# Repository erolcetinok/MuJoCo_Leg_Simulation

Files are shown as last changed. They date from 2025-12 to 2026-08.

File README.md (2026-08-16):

# MuJoCo Quadruped

A 3-DoF-per-leg quadruped with a tight simulation ↔ hardware parallel: one
MuJoCo model, one set of kinematics and gait code, and a backend abstraction so
the same command stream drives the simulator, real Dynamixels, or both at once.

**Current state:** the full 12-DOF software stack is written and verified in
simulation. One physical leg has been driven end-to-end on real hardware. The
four-legged robot has not been assembled yet — that's the next job.

> **Coming back to this after a while?** Read **`docs/STATUS.md`** first — it's
> the dated catch-up page (what works, what's only ever run in sim, what's next).
> Then **`docs/HANDBOOK.md`** for how the code is organised.

---

## Layout

```
configs/robot.yaml      single source of truth (joints, limits, offsets, bauds)
description/            MJCF + STL meshes (MuJoCo-Menagerie convention)
firmware/               Arduino sketches (ARCHIVED); robot_config.h is generated
scripts/                every command you run, plus codegen
src/quadruped/          the importable library
  ├── config.py         generated dataclass mirroring robot.yaml
  ├── kinematics/       fk, ik (closed-form), jacobian (DLS IK + foot force)
  ├── control/          trajectory.py, gait.py
  ├── backends/         RobotBackend ABC: Mujoco, Arduino, Dynamixel, Mirror
  ├── calibration.py    tick math, YAML patching, the guided calibration routine
  ├── cli_args.py       argparse glue shared by scripts/ (backend flags, parsers)
  ├── sim/              MuJoCo loader with YAML-consistency assertions
  └── gui/              Dear PyGui app + embedded MuJoCo renderer
tests/                  pytest
cad/                    CAD source (e.g. thigh.3mf)
```

**`scripts/` holds things you run; `src/quadruped/` holds things you import.**
There are no `quad-*` console scripts — a command is a file, and you run it with
your active interpreter, which is what you want when MuJoCo is involved.

## Quickstart

```bash
python -m venv .venv && source .venv/bin/activate
pip install -e '.[dev,gui]'      # for the dependencies; commands self-bootstrap
pytest
python scripts/codegen.py --check   # generated artifacts match robot.yaml?
```

> **macOS: windowed commands need `mjpython`, not `python`.** MuJoCo's
> interactive viewer must own the main thread. That means `view.py`, `ik_demo.py`,
> anything with `--viewer`, and `gui.py --viewer external`. Everything else —
> including plain `python scripts/gui.py`, whose embedded viewer renders
> offscreen — runs under normal `python`. `mjpython` ships with the mujoco wheel.

```bash
# Simulation only — safe, no hardware needed
python scripts/send_foot.py 20 -175 -50 --dry-run       # IK only, prints angles
mjpython scripts/send_foot.py 20 -175 -50 --backend sim --viewer
mjpython scripts/view.py --model quad
mjpython scripts/ik_demo.py --path step
python scripts/gait_demo.py --gait trot --vx 40

# Hardware — U2D2, in bringup order (see docs/hardware_bringup.md)
export SERIAL_PORT=/dev/ttyUSB0
python scripts/dxl_scan.py                              # do all 12 enumerate?
python scripts/calibrate.py --leg FL                    # guided sign/offset wizard
python scripts/calibrate.py --verify --leg FL           # did it take?
python scripts/swing_hw.py --leg FL --backend dxl --rate 33 --loop
python scripts/gait_demo.py --backend mirror --rate 33

# Sim + hardware in lockstep
mjpython scripts/send_foot.py 20 -175 -50 --backend mirror --viewer

# Slider GUI (Dear PyGui + embedded MuJoCo render)
python scripts/gui.py                                   # sim, embedded viewer
python scripts/gui.py --backend mirror                  # sim + leg together
python scripts/gui.py --backend dxl --viewer none       # sliders only
```

> **GUI viewer modes:** `embedded` (default) renders MuJoCo offscreen into a Dear
> PyGui texture — one window, one process, no second GLFW context, reliable on
> macOS. `external` launches MuJoCo's passive viewer in its own window (mouse
> camera control, but the dual-GLFW setup is fragile on macOS). `none` is
> slider-only.

## Backends

`quadruped.backends.RobotBackend` is the abstraction; pick one with `--backend`
and nothing downstream branches on the choice.

| `--backend` | Class | What it does |
| --- | --- | --- |
| `sim` | `MujocoBackend` | Writes joint angles straight to `data.qpos` and runs `mj_forward`. **Kinematic — physics is bypassed**, so it shows geometry and reach, not balance. |
| `dxl` | `DynamixelBackend` | U2D2 + DYNAMIXEL SDK, direct USB→bus. Pings all 12 on connect and checks every SDK return code. Sync read/write, present current, `foot_force(leg)`, health status. Written and unit-tested; **not yet run against a real bus.** |
| `mirror` | `MirrorBackend` | Fans one command to sim + the U2D2 together. |

`ArduinoBackend` (the UNO/SoftwareSerial bridge that brought up the first leg) is
archived: still importable, no longer reachable from a `--backend` string, and
none of the safety machinery above applies to it. See `firmware/README.md`.

## Editing the robot configuration

Joint limits, motor IDs, baud rates, zero offsets, and link lengths live in
**`configs/robot.yaml`**. Two artifacts are generated from it and committed:

- `firmware/leg_controller/robot_config.h` — `#include`d by the sketch
- `src/quadruped/config.py` — frozen dataclass imported by the package

After editing the YAML, run `python scripts/codegen.py`. `--check` mode fails if
either artifact has drifted; install the bundled hook to make drift a commit
error:

```bash
pip install pre-commit && pre-commit install
```

## Documentation

`docs/` is gitignored — it lives on this machine only, not in the repo.

| File | What it's for |
| --- | --- |
| `docs/STATUS.md` | **Start here.** Dated state of the project, what's hardware-proven vs sim-only, open gaps, next action. |
| `docs/HANDBOOK.md` | How the codebase is organised and how to work in it: mental model, repo map, the two pipelines, "I want to…" recipes, debugging playbook. |
| `docs/CLI.md` | Every command, every flag, when to reach for it. |
| `docs/INVERSE_KINEMATICS.md` | Full derivation of the closed-form solver, plus the Jacobian / DLS / foot-force math. |
| `docs/hardware_bringup.md` | **The build doc.** Components, wiring diagram, gauge per connection, bringup runbook. |
| `docs/power_rationale.md` | Why those parts, what was cut, research sources. |
| `firmware/README.md` | Arduino UNO bridge path (ARCHIVED), end to end. |

## Hardware

The hardware is a Raspberry Pi 5 + U2D2 driving twelve XL430-W250 servos.
`docs/hardware_bringup.md` has the components, the wiring diagram with a gauge per
connection, and the ordered bringup runbook. That stack is final; all remaining
work on this project is software. The Arduino UNO R3 + Dynamixel Shield bridge
that brought up the first leg is archived in `firmware/README.md`.

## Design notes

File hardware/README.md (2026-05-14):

# Single-leg hardware setup

Start-to-finish bring-up for the 3-DoF leg: three daisy-chained Dynamixels driven by an Arduino UNO R3, commanded over USB from your Mac. Joint order everywhere is **shoulder → wing → knee**, same as `meshes/single_leg.xml`.

The Arduino's onboard USB is **flash-only** for this project. Host comms (commands and replies) go through a small USB-to-TTL adapter wired to the Arduino's D7/D8 pins. The reason: on UNO R3, the Dynamixel Shield and the onboard USB-UART chip both live on the same hardware UART (D0/D1) and electrically fight each other for D0 — you cannot reliably read host bytes through the Arduino's USB while the shield is driving the DXL bus. See §5 for the full explanation. The adapter sidesteps the problem cleanly by putting host comms on a second, dedicated serial path that ROBOTIS designed the shield for.

---

## 1. Parts

| Part | Notes |
|---|---|
| **Arduino UNO R3** | ATmega328P. Onboard USB used for flashing only. |
| **ROBOTIS DYNAMIXEL Shield** | TTL half-duplex driver + screw terminals + UART switch + Dynamixel power switch. |
| **3 × XL430-W250-T** servos | Daisy-chained. IDs **1 / 2 / 3** (shoulder / wing / knee), **Protocol 2.0**, **baud 115 200**. |
| **3-pin TTL JST cables** | XL430 uses TTL only — **never** the 4-pin RS-485 port on the shield. |
| **USB-to-TTL adapter** | CP2102, CH340, or FTDI. Any cheap module from Amazon. Carries host commands and replies. |
| **3× M/F jumper wires** | "Dupont" cables to connect adapter ↔ Arduino. |
| **Bench supply** | **6.5–12.0 V** (XL430's spec — the shield itself accepts 5–24 V, but the motors don't), ~5 A capable for three XL-class motors under load. **Do not exceed 12.0 V.** |
| **USB-B cable** | UNO R3 to your Mac (flashing). |
| **USB-A cable for the adapter** | Whatever the adapter takes (USB-A or USB-C). |

Official references (only consult if something doesn't match below):
- [ROBOTIS DYNAMIXEL Shield](https://emanual.robotis.com/docs/en/parts/interface/dynamixel_shield/) — switches, jumpers, connectors.
- [XL430-W250-T](https://emanual.robotis.com/docs/en/dxl/x/xl430-w250/) — voltage, control table.

---

## 2. Mac-side install

1. Install [Arduino IDE 2](https://www.arduino.cc/en/software).
2. **Tools → Board → Boards Manager** → install **Arduino AVR Boards** (it's usually pre-installed; Arduino UNO appears under it).
3. **Tools → Manage Libraries** → install **Dynamixel2Arduino**.
4. From the repo root (the directory containing `requirements.txt`, one level above `hardware/`): `pip install -r requirements.txt` — needed for the helper scripts in `scripts/`.
5. macOS bundles drivers for CP2102 and FTDI out of the box (macOS 11+). For CH340 modules, install [WCH's signed driver](https://www.wch-ic.com/downloads/CH34XSER_MAC_ZIP.html) if your adapter doesn't enumerate.

---

## 3. Configure the servos (IDs, baud, protocol)

Each motor must end up at **ID 1 / 2 / 3**, **baud 115 200**, **Protocol 2.0**. Factory defaults are **ID 1, baud 57 600** — three fresh XL430s on the same bus will all answer to ID 1 and collide, which is why you configure one motor at a time below.

> Why 115 200 and not 1 Mbps (the XL430's nominal max)? Because the hardware Serial bus only carries DXL traffic now (host is on the adapter), 1 Mbps is technically usable — but motors and sketches currently default to 115 200 and there's no benefit at this scale. Stick with 115 200 unless you have a reason.

**You need the shield powered and wired first** — do section 4, then come back here before uploading `leg_controller.ino`.

Use the repo-local helper sketch `hardware/configure_motor/configure_motor.ino`. It probes the motor across 57 600 / 115 200 / 1 000 000, sets it to your target ID, then changes its baud to 115 200 — all in one upload. Output prints to the adapter's terminal at **57 600** (host link baud — see §5).

Procedure — repeat three times:

1. **Disconnect all motors except the one you're configuring.** Plug only motor #1 (or #2 or #3 — they're all identical at this point) into the shield's TTL jack.
2. Open `hardware/configure_motor/configure_motor.ino`.
3. Edit `#define SOURCE_ID` (match the motor's current ID, or 1 for factory-fresh) and `#define TARGET_ID` — **1** for shoulder, **2** for wing, **3** for knee.
4. Set UART switch to **Upload**, click **Upload** in the IDE.
5. Flip UART switch to **DYNAMIXEL**, press **RESET**, wait ~3 seconds.
6. Open a terminal on the adapter's port at **57600** baud (`python scripts/usb_console.py` does this, or any terminal of your choice). You should see `OK: motor at ID <n>, baud 115200` — the 115200 here is the *motor's* baud, which is independent of the host link.
7. Unplug that motor, plug in the next one, change `TARGET_ID`, repeat from step 4.

If you see `FAIL: no motor at ID <n> (tried baud 57600, 115200, 1000000)`, the motor is at an unexpected baud (run `find_motor.ino`), or power/cable/switch isn't right. If you see `FAIL: setID` or `FAIL: setBaudrate`, power-cycle the motor and try again — partial configuration is normal and the sketch handles it.

---

## 4. Physical assembly (power OFF)

1. Stack the **Dynamixel Shield** onto the UNO R3. Press until fully seated.
2. **Remove the VIN jumper cap** from the shield ("Disconnect VIN" mode) so Dynamixel power comes only from the shield's screw terminals, not the Arduino VIN path.
3. Wire bench supply **+ / −** to the shield's Dynamixel power screw terminals, matching the silkscreen exactly. Wrong polarity destroys hardware. Leave the supply OFF.
4. Daisy-chain the servos: **shield's 3-pin TTL JST socket → servo 1 (in) → servo 1 (out) → servo 2 (in) → servo 2 (out) → servo 3 (in)**. Mechanical order does not set IDs — that's done in section 3.
   - Use a **3-pin TTL** jack on the shield. The 4-pin RS-485 jack will not work with XL430-T.
5. Wire the **USB-to-TTL adapter** to the shield's exposed pin headers using three jumper wires:
   - adapter **TX**  → Arduino **D7**
   - adapter **RX**  → Arduino **D8**
   - adapter **GND** → Arduino **GND**
   - adapter **VCC** → **leave disconnected** (Arduino is powered via its own USB).
6. Plug both USB cables into your Mac:
   - **Arduino USB-B** → flashing.
   - **Adapter USB**   → host commands + sketch output.

```
   [ USB-to-TTL adapter ]                      [ Dynamixel Shield ]
     TX RX GND                                 ← 3-pin TTL JST to servos
      |  |  |
      |  |  └─── Arduino GND
      |  └─────── Arduino D8  (sketch TX)
      └────────── Arduino D7  (sketch RX)
                          ↑
                  [ Arduino UNO R3 ]
                          ↑
                       USB-B to Mac (flashing only)
```

---

## 5. How the dual-serial setup works (read before uploading)

UNO R3 has one hardware UART (`Serial` on D0/D1). The Dynamixel Shield uses those same pins for the DXL bus. **At runtime, the hardware Serial carries DXL bus traffic only** — the shield's transceiver actively drives D0/D1, and any other source on those pins gets electrically overridden.

That's why host comms go through `SoftwareSerial(7, 8)` and the USB-to-TTL adapter on D7/D8. The adapter exposes its own `/dev/cu.usbserial*` (or `/dev/cu.SLAB_USBtoUART`) port on your Mac, and that's the port your terminal, `send_angles.py`, and `jog.py` talk to. The Arduino's onboard USB-B (`/dev/cu.usbmodem*`) is used only for flashing.

**Host link runs at 57 600 baud.** All sketches and Python scripts default to this. `SoftwareSerial` on a 16 MHz AVR is too unreliable at 115 200 in practice — bytes get dropped or corrupted, especially on the Mac→Arduino direction. 57 600 is the documented fallback and works cleanly. The DXL bus on hardware Serial stays at 115 200, independent of the host link.

What this means in practice:
- The shield's **UART switch sits on DYNAMIXEL** during normal operation. Only flip to Upload for flashing.
- **Do not try to talk to the Arduino via its onboard USB monitor at runtime.** It's wired into the same UART the shield uses, so anything you type there gets blocked by the shield's transceiver. The adapter is the only host-comm path.
- `SoftwareSerial` occasionally still injects phantom noise bytes before a real line begins; `leg_controller.ino`'s loop discards anything before the `q,` prefix to defend against this.
- `sscanf("%f", ...)` is **not linked** in the default Arduino AVR build — `leg_controller.ino` parses floats with `strtod` instead. Don't switch back to `sscanf %f`; it'll silently fail.

---

## 6. Upload firmware

1. Open `hardware/leg_controller/leg_controller.ino` in Arduino IDE.
2. **Tools → Board → Arduino AVR Boards → Arduino UNO**.
3. **Tools → Port** → the **Arduino's** USB device (`/dev/cu.usbmodem...`). This is for flashing only; not the adapter's port.
4. Set UART switch on shield to **Upload**.
5. Click **Upload**. Wait for it to finish.
6. Set UART switch to **DYNAMIXEL**.
7. **Support the leg by hand** — when the first command lands, motors will snap to whatever position you send. Don't let it whip into something.
8. Turn the bench supply **ON** (correct voltage), then turn the shield's **Dynamixel power switch ON**.
9. Press **RESET** on the Arduino once.

---

## 7. Verify the controller is alive

Open a terminal on the **adapter's** port at **57600** baud. The easiest way:

```bash
python scripts/usb_console.py --port /dev/cu.usbserial-XXXX
```

(or run `python scripts/usb_console.py --list` to see what's plugged in — pick the adapter's port, not the Arduino's `/dev/cu.usbmodem*`).

Expected output after reset:

```
the controller is ready
dynamixels ready
mode: usb command (q,q1,q2,q3)
```

Then send `q,0.0,0.0,0.0` + Enter (line ending Newline). Reply should be `ok 0.00 0.00 0.00` and the leg snaps to the zero pose.

**If the terminal is blank or shows nothing:** baud rate or wrong port. Confirm 57 600 and that you picked the adapter's port. If still blank, double-check the three jumper wires (TX↔D7, RX↔D8, GND↔GND).

**If you see `? no servo ID <n>`** for any motor: IDs / baud / protocol don't match the firmware, or UART switch is still on Upload, or shield power is off, or the cable is in the RS-485 jack. Re-check sections 3, 4, and 6.

---

## 8. Drive the leg from Python

One-shot:

```bash
python scripts/send_angles.py 0.0 0.0 0.0 --port /dev/cu.usbserial-XXXX
```

Or set the port once per terminal session:

```bash
export SERIAL_PORT=/dev/cu.usbserial-XXXX
python scripts/send_angles.py 0.1 -0.2 0.5
```

Interactive (no per-command lag — port stays open):

```bash
python scripts/jog.py --port /dev/cu.usbserial-XXXX
```

```
> 0 0 0
  ok 0.00 0.00 0.00
> 0.5 -0.3 0.2
  ok 0.50 -0.30 0.20
```

`scripts/usb_console.py` is a terminal replacement for Arduino Serial Monitor — useful for one-off inspection. All three scripts default to baud **57 600** to match the sketch.

---

## 9. Protocol

- One line per command: `q,<q1>,<q2>,<q3>`, radians, newline-terminated.
- Reply: `ok <q1> <q2> <q3>` (echo of clamped values), or `? bad format` / `? no servo ID <n>`.
- Joint limits (radians, enforced by the Arduino):

  | Joint | Min | Max |
  |-------|-----|-----|
  | Shoulder | −π/2 | +π/2 |
  | Wing | −0.873 (≈ −50°) | +0.873 (≈ +50°) |
  | Knee | −2.007 (≈ −115°) | +π/2 |

Limits match `meshes/single_leg.xml`.

Motion speed is firmware-set, not commanded: `leg_controller.ino` writes `PROFILE_VELOCITY = 40` to each motor in `setup()`. Edit that constant in the sketch if you want faster/slower trajectories — the Python side has no speed parameter.

---

## 10. Calibration

`leg_controller.ino` ships with `OFFSET_SHOULDER_DEG = OFFSET_WING_DEG = OFFSET_KNEE_DEG = 180.0f`. That maps `q = 0 rad` to motor position 180° — the geometric middle of `OP_POSITION`'s 0–360° range. Around that neutral, each joint's full radian limit lands inside the motor's reachable range:

| Joint | Range from q=0 | Motor degrees |
|---|---|---|
| Shoulder | ±π/2 (±90°) | 90°–270° |
| Wing | ±0.873 (±50°) | 130°–230° |
| Knee | −2.007 to +π/2 (−115° to +90°) | 65°–270° |

**Physical assembly assumption:** when you mount the leg links to the horns, do it with the motor sitting at 180° (its electrical midpoint). Then "q=0 across the board" produces the sim's zero pose mechanically.

If you remount a motor or the sim's zero diverges from the physical neutral, recalibrate by editing the three `OFFSET_*_DEG` constants:

1. Power the bus, leave the motors **torque off** (or just observe present positions before commands move them).
2. By hand, move the leg to the sim's zero pose.
3. Read the boot-time `ID <n> pos deg=...` line printed by `setup()` — that's the motor's current degree value.
4. Use that value as the new `OFFSET_*_DEG` for that joint.

---

## 11. ~~Known issue — knee can't reach negative angles yet~~ Resolved

Previously, the knee's `−2.007 rad (≈ −115°)` minimum was unreachable because `OP_POSITION` is single-turn 0–360° and negative degrees clamp to 0. The 180° offset in §10 fixes this: `−115°` from neutral lands at motor `65°`, well inside the range. No `OP_EXTENDED_POSITION` switch needed.

---

## 12. Safety

- **Do not exceed 12.0 V** on the Dynamixel bus.
- **Do not hot-plug Dynamixel cables** while shield power is on.
- **Polarity** on the shield's power terminals must match the silkscreen.
- Restrain the leg before the first command — motors snap to goal positions immediately.

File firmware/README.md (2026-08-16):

# Arduino UNO bridge — hardware setup (ARCHIVED)

> **This path is retired.** The robot runs Raspberry Pi 5 + U2D2, driving the
> servos directly over the DYNAMIXEL SDK — see `docs/hardware_bringup.md` for the
> BOM and bringup order, and `docs/power_and_electronics.md` for the power chain.
> `--backend hw` no longer exists; `dxl` and `mirror` are the hardware choices.
>
> Everything here still works and is what the first leg was brought up on, so it
> is kept for the old UNO rig. It gets no new features, and the safety work added
> for the U2D2 path (ping-on-connect, stand-up ramp, e-stop freeze, torque
> release, health monitoring) is **not** present on this path.

Start-to-finish bring-up for the Arduino path: up to twelve daisy-chained
Dynamixels driven by an Arduino UNO R3, commanded over USB from your Mac.
Joint order everywhere is the canonical YAML order — legs **FL, FR, BL, BR** ×
joints **shoulder, wing, knee** — the same order used by the wire format, the
`syncWrite` packet, and `configs/robot.yaml`.

If you're bringing up a single leg on the bench, wire only FL (IDs 1-3); the
sketch reports `? no servo ID <n>` for the absent motors at boot and keeps
going.

The Arduino's onboard USB is **flash-only** for this project. Host comms (commands and replies) go through a small USB-to-TTL adapter wired to the Arduino's D7/D8 pins. The reason: on UNO R3, the Dynamixel Shield and the onboard USB-UART chip both live on the same hardware UART (D0/D1) and electrically fight each other for D0 — you cannot reliably read host bytes through the Arduino's USB while the shield is driving the DXL bus. See §5 for the full explanation. The adapter sidesteps the problem cleanly by putting host comms on a second, dedicated serial path that ROBOTIS designed the shield for.

---

## 1. Parts

| Part | Notes |
|---|---|
| **Arduino UNO R3** | ATmega328P. Onboard USB used for flashing only. |
| **ROBOTIS DYNAMIXEL Shield** | TTL half-duplex driver + screw terminals + UART switch + Dynamixel power switch. |
| **12 × XL430-W250-T** servos | Daisy-chained. IDs **1-12** in per-leg blocks (FL 1-3, FR 4-6, BL 7-9, BR 10-12), each block shoulder / wing / knee. **Protocol 2.0**, **baud 115 200**. |
| **3-pin TTL JST cables** | XL430 uses TTL only — **never** the 4-pin RS-485 port on the shield. |
| **USB-to-TTL adapter** | CP2102, CH340, or FTDI. Any cheap module from Amazon. Carries host commands and replies. |
| **3× M/F jumper wires** | "Dupont" cables to connect adapter ↔ Arduino. |
| **Bench supply** | **6.5–12.0 V** (XL430's spec — the shield itself accepts 5–24 V, but the motors don't). ~5 A is enough for one leg on the bench; a full twelve-motor robot needs far more headroom — see `docs/power_and_electronics.md`. **Do not exceed 12.0 V.** |
| **USB-B cable** | UNO R3 to your Mac (flashing). |
| **USB-A cable for the adapter** | Whatever the adapter takes (USB-A or USB-C). |

Official references (only consult if something doesn't match below):
- [ROBOTIS DYNAMIXEL Shield](https://emanual.robotis.com/docs/en/parts/interface/dynamixel_shield/) — switches, jumpers, connectors.
- [XL430-W250-T](https://emanual.robotis.com/docs/en/dxl/x/xl430-w250/) — voltage, control table.

---

## 2. Mac-side install

1. Install [Arduino IDE 2](https://www.arduino.cc/en/software).
2. **Tools → Board → Boards Manager** → install **Arduino AVR Boards** (it's usually pre-installed; Arduino UNO appears under it).
3. **Tools → Manage Libraries** → install **Dynamixel2Arduino**.
4. From the repo root (the directory containing `pyproject.toml`, one level above `firmware/`): `pip install -e .` — installs the `quadruped` Python package and pulls in pyserial/numpy/mujoco for the host-side scripts.
5. macOS bundles drivers for CP2102 and FTDI out of the box (macOS 11+). For CH340 modules, install [WCH's signed driver](https://www.wch-ic.com/downloads/CH34XSER_MAC_ZIP.html) if your adapter doesn't enumerate.

---

## 3. Configure the servos (IDs, baud, protocol)

Each motor must end up at a **unique ID in 1-12**, **baud 115 200**, **Protocol 2.0**. Factory defaults are **ID 1, baud 57 600** — fresh XL430s on the same bus will all answer to ID 1 and collide, which is why you configure one motor at a time below.

The ID map is fixed by `configs/robot.yaml` and must match exactly:

| Leg | Shoulder | Wing | Knee |
|-----|---|---|---|
| FL  | 1 | 2 | 3 |
| FR  | 4 | 5 | 6 |
| BL  | 7 | 8 | 9 |
| BR  | 10 | 11 | 12 |

Label each motor physically as you configure it. Twelve identical servos on a bench with no labels is a bad afternoon.

> Why 115 200 and not 1 Mbps (the XL430's nominal max)? Because the hardware Serial bus only carries DXL traffic now (host is on the adapter), 1 Mbps is technically usable — but motors and sketches currently default to 115 200 and there's no benefit at this scale. Stick with 115 200 unless you have a reason.

**You need the shield powered and wired first** — do section 4, then come back here before uploading `leg_controller.ino`.

> Joint limits, motor IDs, baud rates, and zero offsets all live in `configs/robot.yaml` and are codegen'd into `firmware/leg_controller/robot_config.h` (which the sketch `#include`s). To change any of them, edit the YAML and run `python scripts/codegen.py` — do not hand-edit the `.h` file.

Use the repo-local helper sketch `firmware/configure_motor/configure_motor.ino`. It probes the motor across 57 600 / 115 200 / 1 000 000, sets it to your target ID, then changes its baud to 115 200 — all in one upload. Output prints to the adapter's terminal at **57 600** (host link baud — see §5).

Procedure — repeat once per motor (up to twelve times):

1. **Disconnect all motors except the one you're configuring.** Plug only that motor into the shield's TTL jack — they're all identical at this point.
2. Open `firmware/configure_motor/configure_motor.ino`.
3. Edit `#define SOURCE_ID` (match the motor's current ID, or 1 for factory-fresh) and `#define TARGET_ID` — the value from the ID table above.
4. Set UART switch to **Upload**, click **Upload** in the IDE.
5. Flip UART switch to **DYNAMIXEL**, press **RESET**, wait ~3 seconds.
6. Open a terminal on the adapter's port at **57600** baud (`python scripts/usb_console.py` does this, or any terminal of your choice). You should see `OK: motor at ID <n>, baud 115200` — the 115200 here is the *motor's* baud, which is independent of the host link.
7. Unplug that motor, plug in the next one, change `TARGET_ID`, repeat from step 4.

If you see `FAIL: no motor at ID <n> (tried baud 57600, 115200, 1000000)`, the motor is at an unexpected baud (run `find_motor.ino`), or power/cable/switch isn't right. If you see `FAIL: setID` or `FAIL: setBaudrate`, power-cycle the motor and try again — partial configuration is normal and the sketch handles it.

---

## 4. Physical assembly (power OFF)

1. Stack the **Dynamixel Shield** onto the UNO R3. Press until fully seated.
2. **Remove the VIN jumper cap** from the shield ("Disconnect VIN" mode) so Dynamixel power comes only from the shield's screw terminals, not the Arduino VIN path.
3. Wire bench supply **+ / −** to the shield's Dynamixel power screw terminals, matching the silkscreen exactly. Wrong polarity destroys hardware. Leave the supply OFF.
4. Daisy-chain the servos: **shield's 3-pin TTL JST socket → servo 1 (in) → servo 1 (out) → servo 2 (in) → servo 2 (out) → servo 3 (in)**. Mechanical order does not set IDs — that's done in section 3.
   - Use a **3-pin TTL** jack on the shield. The 4-pin RS-485 jack will not work with XL430-T.
5. Wire the **USB-to-TTL adapter** to the shield's exposed pin headers using three jumper wires:
   - adapter **TX**  → Arduino **D7**
   - adapter **RX**  → Arduino **D8**
   - adapter **GND** → Arduino **GND**
   - adapter **VCC** → **leave disconnected** (Arduino is powered via its own USB).
6. Plug both USB cables into your Mac:
   - **Arduino USB-B** → flashing.
   - **Adapter USB**   → host commands + sketch output.

```
   [ USB-to-TTL adapter ]                      [ Dynamixel Shield ]
     TX RX GND                                 ← 3-pin TTL JST to servos
      |  |  |
      |  |  └─── Arduino GND
      |  └─────── Arduino D8  (sketch TX)
      └────────── Arduino D7  (sketch RX)
                          ↑
                  [ Arduino UNO R3 ]
                          ↑
                       USB-B to Mac (flashing only)
```

---

## 5. How the dual-serial setup works (read before uploading)

UNO R3 has one hardware UART (`Serial` on D0/D1). The Dynamixel Shield uses those same pins for the DXL bus. **At runtime, the hardware Serial carries DXL bus traffic only** — the shield's transceiver actively drives D0/D1, and any other source on those pins gets electrically overridden.

That's why host comms go through `SoftwareSerial(7, 8)` and the USB-to-TTL adapter on D7/D8. The adapter exposes its own `/dev/cu.usbserial*` (or `/dev/cu.SLAB_USBtoUART`) port on your Mac, and that's the port your terminal, `send_angles.py`, and `jog.py` talk to. The Arduino's onboard USB-B (`/dev/cu.usbmodem*`) is used only for flashing.

**Host link runs at 57 600 baud.** All sketches and Python scripts default to this. `SoftwareSerial` on a 16 MHz AVR is too unreliable at 115 200 in practice — bytes get dropped or corrupted, especially on the Mac→Arduino direction. 57 600 is the documented fallback and works cleanly. The DXL bus on hardware Serial stays at 115 200, independent of the host link.

What this means in practice:
- The shield's **UART switch sits on DYNAMIXEL** during normal operation. Only flip to Upload for flashing.
- **Do not try to talk to the Arduino via its onboard USB monitor at runtime.** It's wired into the same UART the shield uses, so anything you type there gets blocked by the shield's transceiver. The adapter is the only host-comm path.
- `SoftwareSerial` occasionally still injects phantom noise bytes before a real line begins; `leg_controller.ino`'s loop discards anything before the `q,` prefix to defend against this.
- `sscanf("%f", ...)` is **not linked** in the default Arduino AVR build — `leg_controller.ino` parses floats with `strtod` instead. Don't switch back to `sscanf %f`; it'll silently fail.

---

## 6. Upload firmware

1. Open `firmware/leg_controller/leg_controller.ino` in Arduino IDE.
2. **Tools → Board → Arduino AVR Boards → Arduino UNO**.
3. **Tools → Port** → the **Arduino's** USB device (`/dev/cu.usbmodem...`). This is for flashing only; not the adapter's port.
4. Set UART switch on shield to **Upload**.
5. Click **Upload**. Wait for it to finish.
6. Set UART switch to **DYNAMIXEL**.
7. **Support the leg by hand** — when the first command lands, motors will snap to whatever position you send. Don't let it whip into something.
8. Turn the bench supply **ON** (correct voltage), then turn the shield's **Dynamixel power switch ON**.
9. Press **RESET** on the Arduino once.

---

## 7. Verify the controller is alive

Open a terminal on the **adapter's** port at **57600** baud. The easiest way:

```bash
python scripts/usb_console.py --port /dev/cu.usbserial-XXXX
```

(or run `python scripts/usb_console.py --list` to see what's plugged in — pick the adapter's port, not the Arduino's `/dev/cu.usbmodem*`).

Expected output after reset:

```
the controller is ready
ID 1 pos ticks=2048 deg=180.00
... (one line per motor found)
dynamixels ready (12 joints)
mode: usb command (q,q0,...,qN-1)
```

Then send twelve zeros + Enter (line ending Newline):

```
q,0,0,0,0,0,0,0,0,0,0,0,0
```

Reply should be `ok` followed by the twelve clamped values, and the legs snap to
the zero pose. Sending fewer than twelve values is rejected with
`? bad format at index <i>` or `? missing comma at index <i>`.

**If the terminal is blank or shows nothing:** baud rate or wrong port. Confirm 57 600 and that you picked the adapter's port. If still blank, double-check the three jumper wires (TX↔D7, RX↔D8, GND↔GND).

**If you see `? no servo ID <n>`** for any motor: IDs / baud / protocol don't match the firmware, or UART switch is still on Upload, or shield power is off, or the cable is in the RS-485 jack. Re-check sections 3, 4, and 6.

---

## 8. Drive the leg from Python

One-shot:

```bash
python scripts/send_angles.py 0.0 0.0 0.0 --port /dev/cu.usbserial-XXXX
```

Or set the port once per terminal session:

```bash
export SERIAL_PORT=/dev/cu.usbserial-XXXX
python scripts/send_angles.py 0.1 -0.2 0.5
```

Interactive (no per-command lag — port stays open), picking the leg:

```bash
python scripts/jog.py --leg FL --backend hw --port /dev/cu.usbserial-XXXX
```

```
> 0 0 0
  ok 0.000 0.000 0.000 ...
> 0.5 -0.3 0.2
  ok 0.500 -0.300 0.200 ...
```

You type three angles; they go to the chosen leg's shoulder/wing/knee, and the
other nine joints hold their cached pose. The reply echoes all twelve.

> `send_angles.py` and `send_foot.py` take the same `--leg` flag, defaulting to
> `FL`.

For a full step cycle rather than static poses, use `scripts/swing_hw.py
--backend hw --rate 33 --loop`.

`scripts/usb_console.py` is a terminal replacement for Arduino Serial Monitor — useful for one-off inspection. All of these default to baud **57 600** to match the sketch.

---

## 9. Protocol

- One line per command: `q,<q0>,<q1>,...,<q11>` — **twelve** radian values,
  newline-terminated, in canonical order (FL, FR, BL, BR × shoulder, wing, knee).
- Reply: `ok` followed by the twelve clamped values. Errors:
  `? bad format; use q,q0,q1,...`, `? bad format at index <i>`,
  `? missing comma at index <i>`, `? no servo ID <n>`, `? syncWrite failed err=<code>`.
- All twelve goals go out in **one `syncWrite` packet**, which is the point of
  the multi-leg refactor — twelve separate `setGoalPosition()` calls would not
  fit the timing budget.
- Joint limits (radians, enforced by the Arduino, identical for every leg):

  | Joint | Min | Max |
  |-------|-----|-----|
  | Shoulder | −π/2 | +π/2 |
  | Wing | −0.873 (≈ −50°) | +0.873 (≈ +50°) |
  | Knee | −2.007 (≈ −115°) | +π/2 |

Limits, IDs, offsets, and directions all come from `robot_config.h`, generated
from `configs/robot.yaml`. They are asserted against the MJCF at model-load
time, so sim and firmware can't silently disagree.

**This link is fire-and-forget by design.** `SoftwareSerial` drops roughly 15%
of host bytes while the DXL bus is busy, so `ArduinoBackend` does not wait for
the `ok` echo — a dropped command is simply superseded by the next one at the
streaming rate. Measured round-trip is ~19 ms, giving a practical ceiling of
**40–50 Hz**; use `--rate 33`. If you need reliable feedback, use the U2D2 path.

Motion speed is firmware-set, not commanded: `leg_controller.ino` writes
`PROFILE_VELOCITY = 0` to each motor in `setup()`. Zero means "no profile" —
the servo goes to each goal as fast as it can, which is what you want when the
host is streaming a smooth trajectory at 33 Hz and the profile would otherwise
fight it. Raise it only for slow, discrete moves.

---

## 10. Calibration

> **Do this with `scripts/calibrate.py` if you have a U2D2.** The guided wizard
> walks a whole leg — offset *and* direction sign — and writes the results
> straight into `configs/robot.yaml`:
>
> ```bash
> python scripts/view.py --model quad &     # visual reference for "zero pose"
> python scripts/calibrate.py --leg FR
> python scripts/codegen.py                 # regenerate robot_config.h, then reflash
> ```
>
> The manual procedure below is the Arduino-path equivalent, and is what FL was
> originally calibrated with on 2026-05-14.

Offsets and direction signs are **per joint**, generated into
`robot_config.h` as `OFFSETS_DEG[N_JOINTS]` and `DIRS[N_JOINTS]` from the
`offset_deg` / `direction` fields in `configs/robot.yaml`. They all currently
ship at `180.0` / `+1`. That maps `q = 0 rad` to motor position 180° — the
geometric middle of `OP_POSITION`'s 0–360° range. Around that neutral, each
joint's full radian limit lands inside the motor's reachable range:

| Joint | Range from q=0 | Motor degrees |
|---|---|---|
| Shoulder | ±π/2 (±90°) | 90°–270° |
| Wing | ±0.873 (±50°) | 130°–230° |
| Knee | −2.007 to +π/2 (−115° to +90°) | 65°–270° |

**Physical assembly assumption:** when you mount the leg links to the horns, do it with the motor sitting at 180° (its electrical midpoint). Then "q=0 across the board" produces the sim's zero pose mechanically.

If you remount a motor or the sim's zero diverges from the physical neutral,
recalibrate that joint:

1. Power the bus, leave the motors **torque off** (or just observe present positions before commands move them).
2. By hand, move the leg to the sim's zero pose.
3. Read the boot-time `ID <n> pos deg=...` line printed by `setup()` — that's the motor's current degree value.
4. Put that value in the joint's `offset_deg` in **`configs/robot.yaml`** (not in the sketch, and not in `robot_config.h` — that file is generated).
5. `python scripts/codegen.py`, then reflash.

If the joint moves the *opposite* way from the model, flip its `direction` from
`1` to `-1` in the same YAML line and regenerate. The firmware applies it as
`deg = DIRS[i] * q[i] * 180/π + OFFSETS_DEG[i]`.

---

## 11. ~~Known issue — knee can't reach negative angles yet~~ Resolved

Previously, the knee's `−2.007 rad (≈ −115°)` minimum was unreachable because `OP_POSITION` is single-turn 0–360° and negative degrees clamp to 0. The 180° offset in §10 fixes this: `−115°` from neutral lands at motor `65°`, well inside the range. No `OP_EXTENDED_POSITION` switch needed.

---

## 12. Safety

- **Do not exceed 12.0 V** on the Dynamixel bus.
- **Do not hot-plug Dynamixel cables** while shield power is on.
- **Polarity** on the shield's power terminals must match the silkscreen.
- Restrain the leg before the first command — motors snap to goal positions immediately.

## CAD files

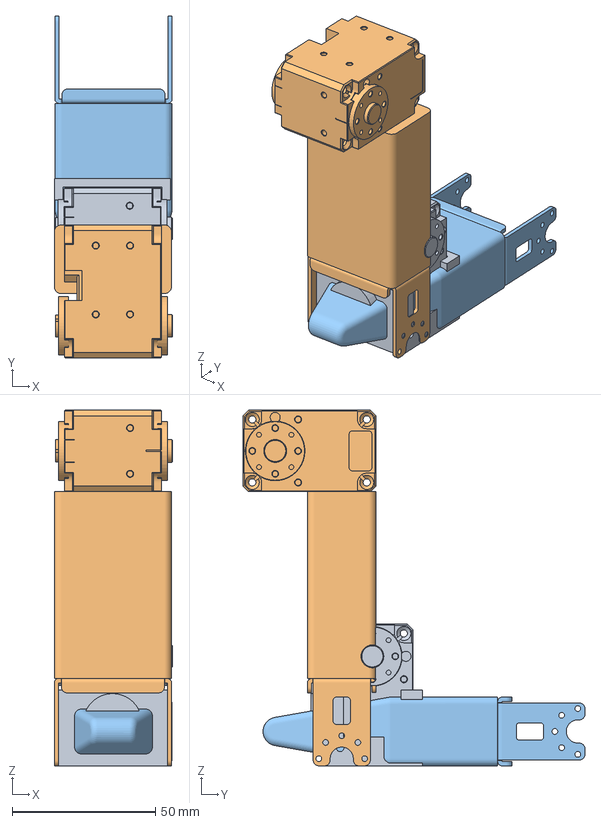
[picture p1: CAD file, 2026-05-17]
cad/thigh.3mf
41.4 x 119.5 x 124.3 mm
shoulder.STL
thigh.STL
foot.STL

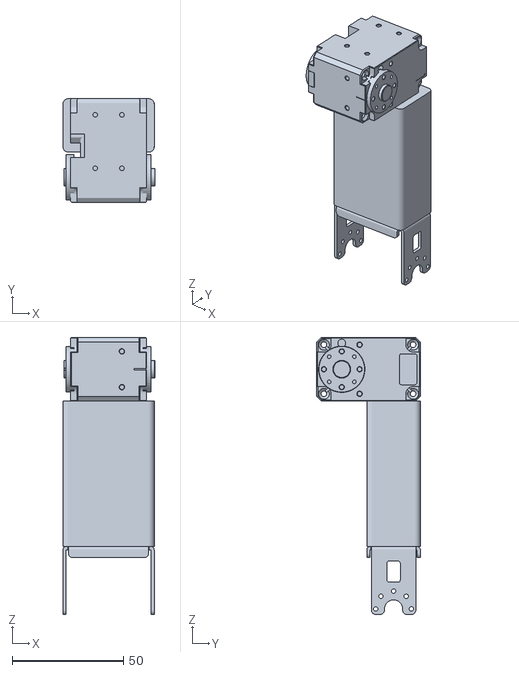
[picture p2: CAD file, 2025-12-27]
description/meshes/thigh.STL
41.4 x 46.5 x 124.3

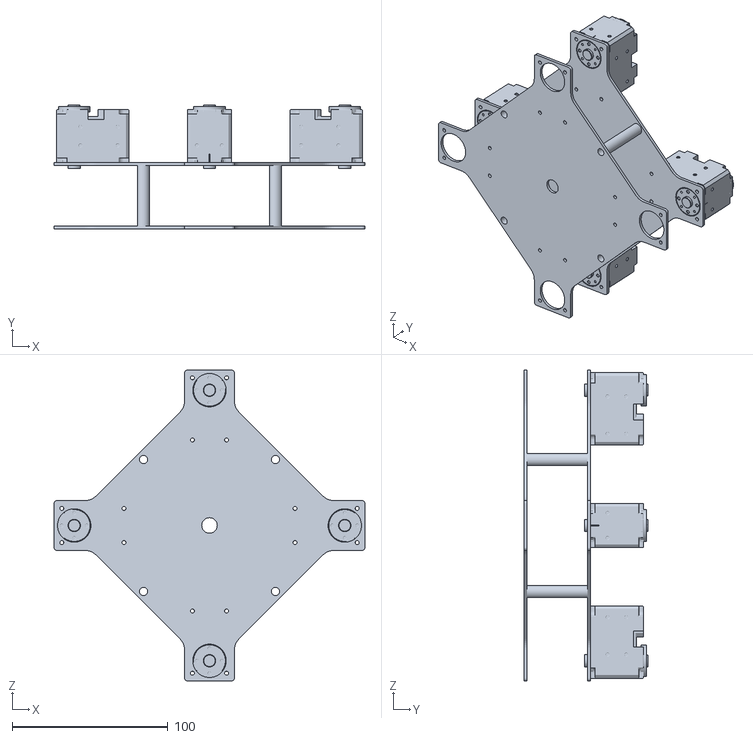
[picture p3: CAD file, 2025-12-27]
description/meshes/body.STL
200.0 x 79.8 x 200.0

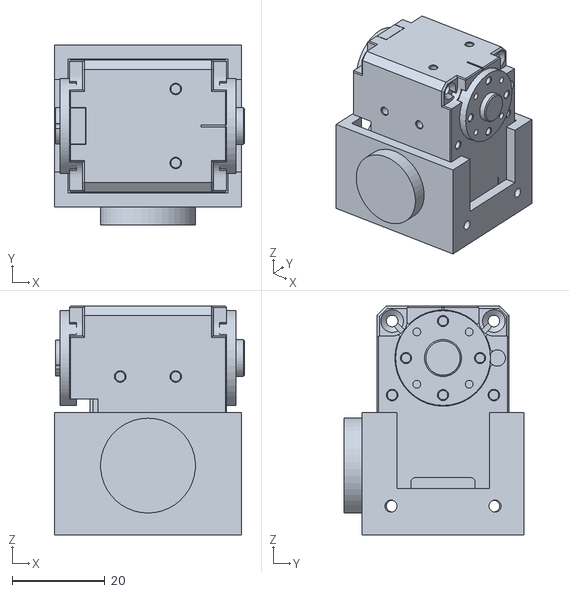
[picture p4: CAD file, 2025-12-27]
description/meshes/shoulder.STL
41.2 x 38.9 x 49.5

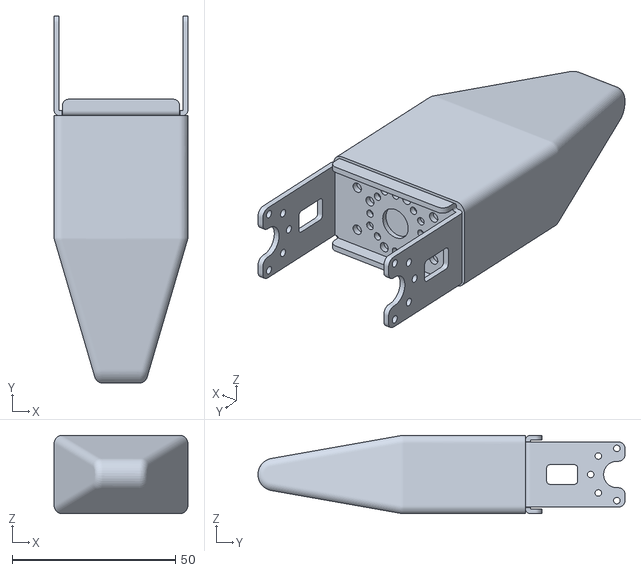
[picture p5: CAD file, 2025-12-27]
description/meshes/foot.STL
41.0 x 112.5 x 24.0

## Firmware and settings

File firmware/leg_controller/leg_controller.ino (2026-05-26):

// Reads joint angles over the USB-to-TTL adapter and drives N_JOINTS dynamixels.
// Protocol: q,<q0>,<q1>,...,<q[N_JOINTS-1]>  (radians, joint order = YAML order
// = FL,FR,BL,BR × shoulder,wing,knee; see robot_config.h for the index map).
//
// Hardware:
//   - Arduino UNO R3 + ROBOTIS Dynamixel Shield + 12× XL430-W250-T motors
//   - CP2102 / CH340 / FTDI USB-to-TTL adapter wired:
//       adapter TX → Arduino D7   (Arduino's SoftwareSerial RX)
//       adapter RX → Arduino D8   (Arduino's SoftwareSerial TX)
//       adapter GND → Arduino GND
//   - Adapter's VCC stays disconnected (Arduino is powered via its own USB).
//
// Two USB connections at runtime:
//   - Arduino USB-B (/dev/cu.usbmodem*)  → flash only; do not use for comms.
//   - Adapter USB    (/dev/cu.usbserial* or /dev/cu.SLAB_USBtoUART)  → host
//                                                                     I/O at
//                                                                     HOST_BAUD
//                                                                     (see
//                                                                     robot_config.h).
//
// UART switch on the shield:
//   - Upload position → flashing the sketch.
//   - DYNAMIXEL position → runtime (shield uses the hardware UART for the
//     DXL bus).
//
// Joint limits, motor IDs, offsets, and bauds all come from robot_config.h,
// generated from ../../configs/robot.yaml by scripts/codegen.py — do not
// hand-edit the .h.
//
// All N_JOINTS goal positions are written to the DXL bus in a single
// syncWrite packet per host line. This is the Stanford Pupper convention
// and cuts bus time vs N_JOINTS separate setGoalPosition() calls, which is
// what frees up the SoftwareSerial RX ISR enough to receive host bytes
// reliably (~15% drop rate seen on the single-leg path was caused by per-motor
// writes blocking the bus).

#include <SoftwareSerial.h>
#include <Dynamixel2Arduino.h>

#include "robot_config.h"

#define MAX_LINE 256              // 12 floats × ~16 chars + commas + 'q,' fits
#define DXL_PROTOCOL_VERSION 2.0f
#define DXL_DIR_PIN 2

// XL430 goal-position control table entry: addr 116, 4 bytes (int32_t ticks).
#define GOAL_POSITION_ADDR 116
#define GOAL_POSITION_LEN  4

SoftwareSerial cmd(7, 8);  // RX=D7 ← adapter TX, TX=D8 → adapter RX

Dynamixel2Arduino dxl(Serial, DXL_DIR_PIN);
using namespace ControlTableItem;

// Pre-built syncWrite descriptor. Reused every line — the param struct is
// large (~200 B), so allocate once at file scope rather than per-call.
typedef struct __attribute__((packed)) {
  int32_t goal_position;
} sw_data_t;

static ParamForSyncWriteInst_t sw_info;
static sw_data_t sw_data[N_JOINTS];

void processLine(char* line);

void setup() {
  cmd.begin(HOST_BAUD);
  dxl.begin(DXL_BAUD);
  dxl.setPortProtocolVersion(DXL_PROTOCOL_VERSION);
  cmd.println("the controller is ready");

  for (int i = 0; i < N_JOINTS; i++) {
    uint8_t id = IDS[i];
    if (!dxl.ping(id)) {
      cmd.print("? no servo ID ");
      cmd.println(id);
      continue;
    }
    dxl.reboot(id);
    delay(300);
    int32_t ticks = dxl.getPresentPosition(id);
    cmd.print("ID ");
    cmd.print(id);
    cmd.print(" pos ticks=");
    cmd.print(ticks);
    cmd.print(" deg=");
    cmd.println(ticks * 360.0f / 4096.0f, 2);
    dxl.torqueOff(id);
    dxl.setOperatingMode(id, OP_POSITION);
    dxl.torqueOn(id);
    // profile_velocity = 0 → no trapezoidal cap; motor tracks each
    // streamed goal as fast as it can. Required for smooth streaming
    // control (Stanford Pupper convention).
    dxl.writeControlTableItem(PROFILE_VELOCITY, id, 0);
  }

  // Build the syncWrite descriptor once. Per-tick we only refresh the
  // goal_position payload, not the ID list.
  sw_info.packet.p_buf = nullptr;
  sw_info.packet.is_completed = false;
  sw_info.addr = GOAL_POSITION_ADDR;
  sw_info.addr_length = GOAL_POSITION_LEN;
  sw_info.id_count = N_JOINTS;
  for (int i = 0; i < N_JOINTS; i++) {
    sw_info.xel[i].id = IDS[i];
    sw_info.xel[i].p_data = (uint8_t*)&sw_data[i].goal_position;
  }

  cmd.print("dynamixels ready (");
  cmd.print(N_JOINTS);
  cmd.println(" joints)");
  cmd.println("mode: usb command (q,q0,...,qN-1)");
}

void loop() {
  static char line[MAX_LINE];
  static int len = 0;

  while (cmd.available() && len < MAX_LINE - 1) {
    char c = cmd.read();
    if (c == '\n' || c == '\r') {
      line[len] = '\0';
      if (len > 0) {
        processLine(line);
      }
      len = 0;
      break;
    }
    // Discard SoftwareSerial noise before the 'q,' command prefix.
    if (len == 0 && c != 'q') continue;
    line[len++] = c;
  }
  if (len >= MAX_LINE - 1) {
    len = 0;
  }
}

void processLine(char* line) {
  // Arduino AVR's default sscanf has no %f support, so parse with strtod.
  if (line[0] != 'q' || line[1] != ',') {
    cmd.println("? bad format; use q,q0,q1,...");
    return;
  }
  float q[N_JOINTS];
  char* p = line + 2;
  char* end;
  for (int i = 0; i < N_JOINTS; i++) {
    q[i] = strtod(p, &end);
    if (end == p) {
      cmd.print("? bad format at index ");
      cmd.println(i);
      return;
    }
    p = end;
    if (i < N_JOINTS - 1) {
      if (*p != ',') {
        cmd.print("? missing comma at index ");
        cmd.println(i);
        return;
      }
      p++;
    }
  }

  // Clamp, apply sign + offset, convert to ticks, stage into the syncWrite
  // payload. Ticks: 0..4095 over 360°, so deg → ticks = deg * 4096 / 360.
  for (int i = 0; i < N_JOINTS; i++) {
    float qi = constrain(q[i], LIMITS[i][0], LIMITS[i][1]);
    float deg = DIRS[i] * qi * 180.0f / PI + OFFSETS_DEG[i];
    sw_data[i].goal_position = (int32_t)(deg * 4096.0f / 360.0f + 0.5f);
  }

  // One packet for all N_JOINTS — the whole point of the multi-leg refactor.
  bool ok = dxl.syncWrite(&sw_info);

  if (ok) {
    cmd.print("ok");
    for (int i = 0; i < N_JOINTS; i++) {
      cmd.print(' ');
      cmd.print(q[i], 3);
    }
    cmd.println();
  } else {
    cmd.print("? syncWrite failed err=");
    cmd.println(dxl.getLastLibErrCode());
  }
}

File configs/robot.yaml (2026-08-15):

robot: quadruped
description_xml: description/quadruped.xml

serial:
  baud_host: 57600 # softwareSerial ceiling on UNO R3
  baud_dxl: 115200

# host-only actuator constants. used by kinematics/jacobian.foot_force to turn the DXL
# present-current into joint torque, then into a cartesian foot force.
actuator:
  # XL430-W250 gear-output torque constant
  torque_constant_nm_per_a: 1.077

# canonical leg order: FL, FR, BL, BR
legs: [FL, FR, BL, BR]

# 12 servos in per-leg ID blocks: FL=1-3, FR=4-6, BL=7-9, BR=10-12
joints:
  # front left
  - {name: shoulder_FL, leg: FL, joint: shoulder, motor_id: 1,  limit_rad: [-1.57079632679,  1.57079632679], offset_deg: 180.0, direction:  1}
  - {name: wing_FL,     leg: FL, joint: wing,     motor_id: 2,  limit_rad: [-0.872664625997, 0.872664625997], offset_deg: 180.0, direction:  1}
  - {name: knee_FL,     leg: FL, joint: knee,     motor_id: 3,  limit_rad: [-2.00712863979,  1.57079632679], offset_deg: 180.0, direction:  1}
  # front right
  - {name: shoulder_FR, leg: FR, joint: shoulder, motor_id: 4,  limit_rad: [-1.57079632679,  1.57079632679], offset_deg: 180.0, direction:  1}
  - {name: wing_FR,     leg: FR, joint: wing,     motor_id: 5,  limit_rad: [-0.872664625997, 0.872664625997], offset_deg: 180.0, direction:  1}
  - {name: knee_FR,     leg: FR, joint: knee,     motor_id: 6,  limit_rad: [-2.00712863979,  1.57079632679], offset_deg: 180.0, direction:  1}
  # back left
  - {name: shoulder_BL, leg: BL, joint: shoulder, motor_id: 7,  limit_rad: [-1.57079632679,  1.57079632679], offset_deg: 180.0, direction:  1}
  - {name: wing_BL,     leg: BL, joint: wing,     motor_id: 8,  limit_rad: [-0.872664625997, 0.872664625997], offset_deg: 180.0, direction:  1}
  - {name: knee_BL,     leg: BL, joint: knee,     motor_id: 9,  limit_rad: [-2.00712863979,  1.57079632679], offset_deg: 180.0, direction:  1}
  # back right
  - {name: shoulder_BR, leg: BR, joint: shoulder, motor_id: 10, limit_rad: [-1.57079632679,  1.57079632679], offset_deg: 180.0, direction:  1}
  - {name: wing_BR,     leg: BR, joint: wing,     motor_id: 11, limit_rad: [-0.872664625997, 0.872664625997], offset_deg: 180.0, direction:  1}
  - {name: knee_BR,     leg: BR, joint: knee,     motor_id: 12, limit_rad: [-2.00712863979,  1.57079632679], offset_deg: 180.0, direction:  1}

# link offsets as 3D vectors (mm), each expressed in its parent joint's frame
# at zero pose. shared across legs, the leg geometry itself is identical.
# only the body→shoulder transform differs (encoded in shoulder body quats
# in description/quadruped.xml).
# FK composes these directly: foot = Rz(t1)*(L1 + Rx(t2)*(L2 + Rx(t3)*L3))
links_mm:
  shoulder_to_wing: [-20.25, -23.25, 21.4]
  wing_to_knee: [0.0, -107.5, -23.25]
  knee_to_foot: [21.0, 0.0, -110.0]

foot_site_offset_mm: [21, -12, 0]
# nominal resting foot in leg-local frame
target_site_offset_mm: [0, -133, -80]

mjcf:
  # MJCF sites are per-leg suffixed: foot_site_FL, target_site_FL, ...
  foot_site_name: foot_site
  target_site_name: target_site
  joint_names:
    - shoulder_joint_FL
    - wing_joint_FL
    - knee_joint_FL
    - shoulder_joint_FR
    - wing_joint_FR
    - knee_joint_FR
    - shoulder_joint_BL
    - wing_joint_BL
    - knee_joint_BL
    - shoulder_joint_BR
    - wing_joint_BR
    - knee_joint_BR

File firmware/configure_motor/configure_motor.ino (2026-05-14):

// One-shot motor configuration for UNO R3 + ROBOTIS Dynamixel Shield.
// Takes a motor currently at SOURCE_ID (auto-detects current baud across
// 57600 / 115200 / 1000000) and sets it to TARGET_ID at TARGET_BAUD.
//
// Connect ONE XL430 at a time. Edit SOURCE_ID and TARGET_ID below, upload,
// flip UART switch to DYNAMIXEL, press RESET, wait a few seconds. Open a
// terminal on the USB-to-TTL adapter's port (/dev/cu.usbserial* or
// /dev/cu.SLAB_USBtoUART) at 115200 baud to see the final status line.
//
// If you don't know the motor's current ID/baud, run
// hardware/tools/find_motor/find_motor.ino first.

#define SOURCE_ID 3   // <<< what the motor is at right now (per find_motor) >>>
#define TARGET_ID 1   // <<< what you want the motor to become >>>

#include <SoftwareSerial.h>
#include <Dynamixel2Arduino.h>

#define DXL_DIR_PIN 2
#define DXL_PROTOCOL_VERSION 2.0f
#define TARGET_BAUD  115200
#define HOST_BAUD    57600

// Bauds to try when probing for the motor's current state. Covers factory-
// fresh (57600), the post-migration value (115200), and the old project
// default (1000000) so motors mid-migration are still detectable.
const uint32_t TRIAL_BAUDS[] = {57600, 115200, 1000000};
const int NUM_TRIAL_BAUDS = sizeof(TRIAL_BAUDS) / sizeof(TRIAL_BAUDS[0]);

SoftwareSerial cmd(7, 8);  // RX=D7 ← adapter TX, TX=D8 → adapter RX
Dynamixel2Arduino dxl(Serial, DXL_DIR_PIN);

void setup() {
  cmd.begin(HOST_BAUD);
  uint32_t source_baud = 0;

  for (int i = 0; i < NUM_TRIAL_BAUDS; i++) {
    dxl.begin(TRIAL_BAUDS[i]);
    dxl.setPortProtocolVersion(DXL_PROTOCOL_VERSION);
    delay(200);
    if (dxl.ping(SOURCE_ID)) {
      source_baud = TRIAL_BAUDS[i];
      break;
    }
  }

  if (source_baud == 0) {
    dxl.begin(TARGET_BAUD);
    cmd.print("FAIL: no motor at ID ");
    cmd.print(SOURCE_ID);
    cmd.println(" (tried baud 57600, 115200, 1000000)");
    cmd.println("Run find_motor.ino to discover the motor's current settings.");
    return;
  }

  // Change ID if needed.
  if (TARGET_ID != SOURCE_ID) {
    dxl.torqueOff(SOURCE_ID);
    if (!dxl.setID(SOURCE_ID, TARGET_ID)) {
      dxl.begin(TARGET_BAUD);
      cmd.println("FAIL: setID");
      return;
    }
  }

  // Change baud if needed.
  if (source_baud != TARGET_BAUD) {
    dxl.torqueOff(TARGET_ID);
    if (!dxl.setBaudrate(TARGET_ID, TARGET_BAUD)) {
      cmd.println("FAIL: setBaudrate (motor at new ID, still at old baud)");
      return;
    }
  }

  // Verify at final settings.
  dxl.begin(TARGET_BAUD);
  delay(200);
  if (dxl.ping(TARGET_ID)) {
    cmd.print("OK: motor at ID ");
    cmd.print(TARGET_ID);
    cmd.print(", baud ");
    cmd.println(TARGET_BAUD);
  } else {
    cmd.println("WARN: configured but final ping failed — power-cycle and rescan");
  }
}

void loop() {}

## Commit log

2025-12-27 added new folders and tings
    [body.STL, foot.STL, shoulder.STL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]
2025-12-27 made changes to python files so i can use joint sliders in MuJoCo
2025-12-27 refactored joint slider implementation in Python files for improved MuJoCo functionality
2026-03-13 starting to work on code for the physical testing of a single leg, have been assembling the actual leg recently
2026-04-11 adjusted so that the primary default board is Arduino Uno Q as opposed to Arduino Mega
2026-05-11 new README with celar instructions and adjustments to leg controlling and position sending, waiting on USB-to-TTL to go further
2026-05-14 hardware refinements, baud switches, changing of joint zeroes, etc.
2026-05-17 reconfigured the entire project for expandability over the upcoming summer
    [body.STL, foot.STL, robot.yaml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]
2026-05-18 cleaning up kinematic stuff so i can do a start to finish implementation
2026-05-19 adjusted single leg xml to get rid of the body and now the yaml and it are aligned
    [robot.yaml]
2026-05-24 added the framework for SwingFootTrajectory
2026-05-25 worked on fixing the trajectory/gait demo for a single leg and it is working now
    [mujoco_backend.py, swing_hw.py]
2026-05-26 configuring for four leg transition
    [robot.yaml]
2026-05-27 continued to configure the project for 4 leg project expansion
2026-06-01 working on adjusting body config
    [robot.yaml]
2026-06-01 making further edits to leg config
    [robot.yaml]
2026-06-01 working on the gait and robot position
    [robot.yaml]
2026-06-03 worked on the backend for the onboard Pi 5 as well as calibration procedure for each dynamixel
2026-07-13 added numerical IK, DLS, and jacobian + foot force
    [robot.yaml]
2026-08-13 added keyboard drivers
2026-08-18 adding pythong script for dynamixel calibration using the pi
